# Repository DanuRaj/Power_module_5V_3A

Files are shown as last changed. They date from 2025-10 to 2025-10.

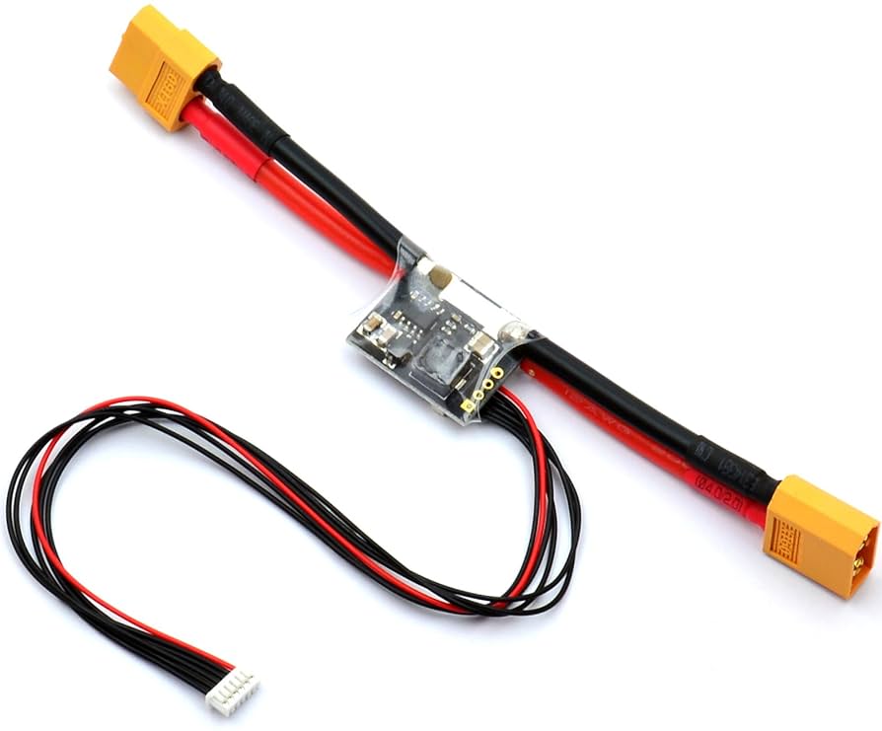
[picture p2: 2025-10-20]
Reference documents/APM BEC module image.jpg

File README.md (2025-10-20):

# Power_module_5V_3A
<p align="left">

</p> 

This power module takes power from the flight battery (usually 6 cell) and steps it down to a stable 5.25V output to power the flight controller. It measures the battery voltage and 
current draw and send this analog data to the flight controller.

## Board Function Description
- Voltage Regulator: A switching power supply (Buck Converter) convert the input voltage (input max 28V) to a steady 5.25V (3A max).
- Current Sensor: A high-side, unipolar current shunt monitor (INA139) from Texas Instruments, used to measure current upto 60A.
- Voltage Divider: A simple circuit scales the battery's high voltage down to a range that the flight controller's analog-to-digital converter (ADC) can safely read.

## Links
- Component Comparision, selection and budget calculation: https://docs.google.com/spreadsheets/d/1E6E3Z39MS1AMKON_rcoMTrBAKxuoQgl9/edit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
- Board version details: https://docs.google.com/spreadsheets/d/1RwYq9DlDa9_kEa9Yjs7iCPJi0Gea4oT7bDzQ82SCQtg/edit?usp=sharing
- Board fabrication batch details: https://docs.google.com/spreadsheets/d/1Ot-wO0kC-6jDttAs3GkX9LXFDDRmeL8QQExoFt7C394/edit?usp=sharing
- Block diagram: https://drive.google.com/file/d/1YQ6c-Lb43SASnWm7NJ7m4_MqnetjV_JF/view?usp=sharing

## Top and bottom images
<p align="left">


</p>

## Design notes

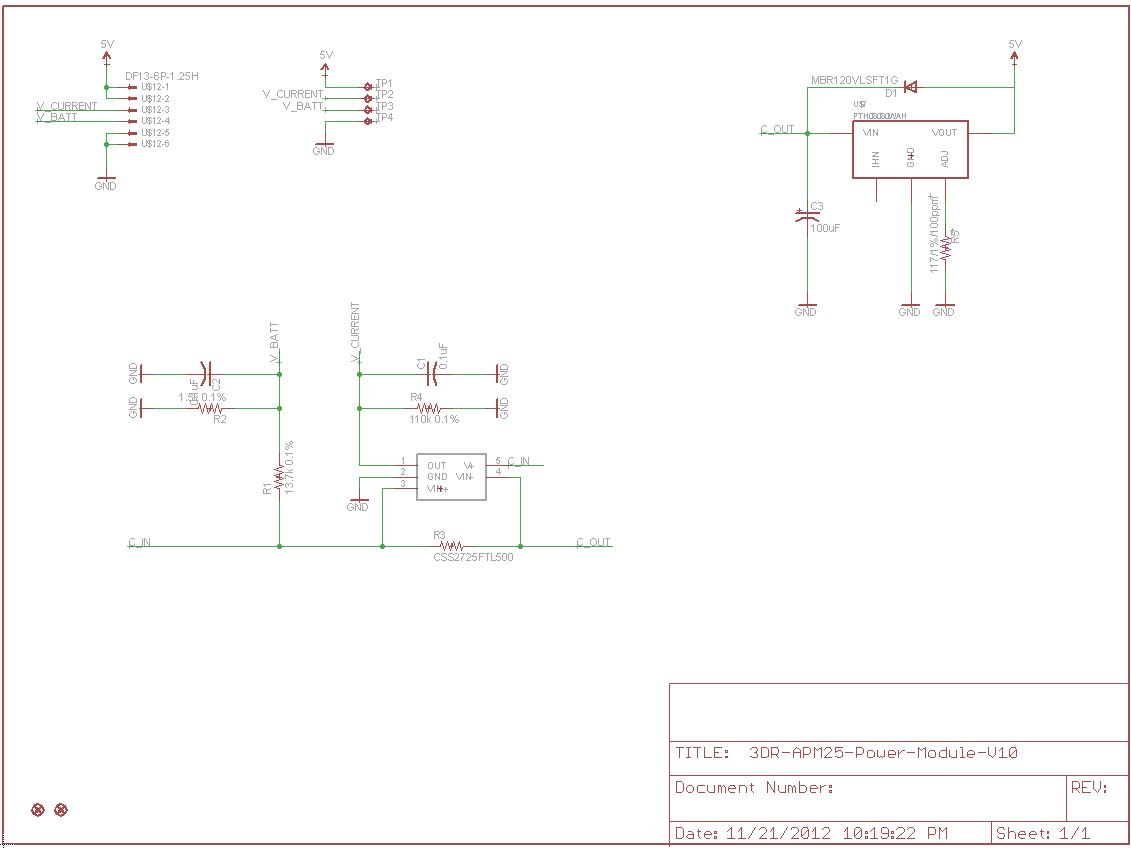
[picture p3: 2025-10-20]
Reference documents/024_21_apm-power-module-schematic.jpg

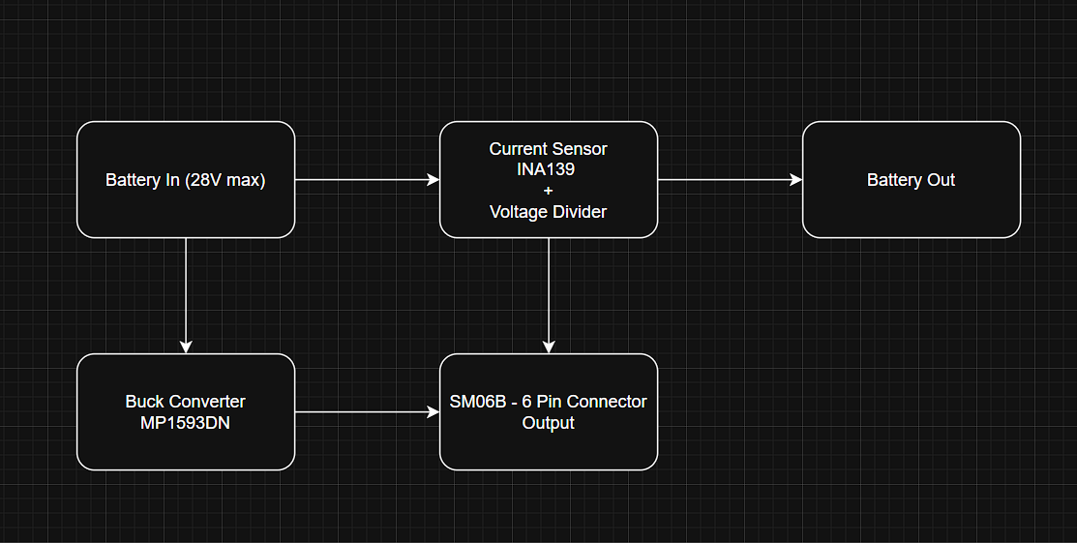
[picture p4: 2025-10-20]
Reference documents/Block Diagram.png

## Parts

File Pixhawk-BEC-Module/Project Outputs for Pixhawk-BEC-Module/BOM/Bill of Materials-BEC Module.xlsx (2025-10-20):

Name | Quantity | Designator | Footprint | MPN | Description
CC0402KRX7R9BB104 | 3 | C1, C2, C8 | CAP_0402 | CC0402KRX7R9BB104 | 50V 100nF X7R ±10% 0402 Multilayer Ceramic Capacitors MLCC - SMD/SMT ROHS
C0402C103K5RACTU | 2 | C3, C9 | CAP_0402 | C0402C103K5RACTU | Multilayer Ceramic Capacitors MLCC - SMD/SMT 50V 0.01uF X7R 0402 10%
CC1210KKX7R9BB106 | 2 | C4, C5 | CAP_1210 | CC1210KKX7R9BB106 | 50V 10uF X7R ±10% 1210 Multilayer Ceramic Capacitors MLCC - SMD/SMT ROHS
GRM32ER71E226ME15L | 2 | C6, C7 | CAP_1210 | GRM32ER71E226ME15L | 22 µF ±20% 25V Ceramic Capacitor X7R 1210 (3225 Metric)
SS34 | 1 | D1 | SMB_ONS | SS34 | Diode 40 V 3A Surface Mount DO-214AB (SMC)
SM06B-GHS-TB | 1 | J1 | CONN_SM06B-GHS-TB_JST | SM06B-GHS-TB | Connector Header Surface Mount, Right Angle 6 position 0.049" (1.25mm)
SRR1260-150M | 1 | L1 | IND_BOURNS_SRR1260 | SRR1260-150M | 15 µH Shielded Drum Core, Wirewound Inductor 5 A 27mOhm Max Nonstandard
PA2512FKE7T0U5E | 1 | R1 | RES_PA2512_YAG-L | PA2512FKE7T0U5E | 500 µOhms ±1% 3W Chip Resistor 2512 (6332 Metric) Anti-Sulfur, Automotive AEC-Q200, Current Sense, Moisture Resistant Metal Element
ERJ-2RKF1372X | 1 | R2 | RES_0402 | ERJ-2RKF1372X | Res Thick Film 0402 13.7K Ohm 1% 0.1W ±100ppm/°C Molded SMD Punched Carrier T/R
ERJ-2GEJ152X | 1 | R3 | RES_0402 | ERJ-2GEJ152X | Res Thick Film 0402 1.5K Ohm 5% 0.1W(1/10W) +/-200ppm/ßC SMD Automotive T/R
ERJ-2GEJ104X | 1 | R4 | RES_0402 | ERJ-2GEJ104X | Res Thick Film 0402 100K Ohm 5% 0.1W(1/10W) +/-200ppm/ßC SMD Automotive T/R
CRGP0402F33K | 1 | R5 | RES_0402 | CRGP0402F33K | Res Thick Film 0402 33K Ohm 1% 0.125W(1/8W) ±100ppm/C Pad SMD T/R Automotive AEC-Q200
CRGP0402F10K | 1 | R6 | RES_0402 | CRGP0402F10K | Res Thick Film 0402 10K Ohm 1% 0.125W(1/8W) ±100ppm/C Pad SMD T/R Automotive AEC-Q200
RK73H1ETTP7501F | 1 | R7 | RES_0402 | RK73H1ETTP7501F | Res Thick Film 0402 7.5K Ohm 1% 0.1W(1/10W) ±100ppm/C Pad SMD Automotive T/R
INA139NA/250 | 1 | U1 | DBV0005A_N | INA139NA/250 | 2.7 to 36V, 440kHz Variable gain current sense amplifier 5-SOT-23 -40 to 125
MP1593DN-LF-Z | 1 | U2 | SOIC8E_MNP | MP1593DN-LF-Z | 3A 28V 385KHz Step-Down Converter

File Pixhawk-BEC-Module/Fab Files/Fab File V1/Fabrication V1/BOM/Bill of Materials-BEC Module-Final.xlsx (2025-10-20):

Bill Of Materials |  |  |  | Bill of Materials for [Bill of Materials-BEC Module.BomDoc]
 |  |  | Source Data From: | Bill of Materials-BEC Module.BomDoc
 |  |  | Project: | Pixhawk-BEC-Module.PrjPCB
 |  |  | Variant: | No Variant
 |  | Report Date:(MM/DD/YY) | 2025-10-09
 |  | Print Date: (MM/DD/YY) | 2025-10-09
Line | Quantity | Designator | Description | Manufacturer 1 | Manufacturer Part Number 1
 | 3 | C1, C2, C8 | 50V 100nF X7R ±10% 0402 Multilayer Ceramic Capacitors MLCC - SMD/SMT ROHS |  | CC0402KRX7R9BB104
 | 2 | C3, C9 | Multilayer Ceramic Capacitors MLCC - SMD/SMT 50V 0.01uF X7R 0402 10% |  | C0402C103K5RACTU
 | 2 | C4, C5 | 50V 10uF X7R ±10% 1210 Multilayer Ceramic Capacitors MLCC - SMD/SMT ROHS |  | CC1210KKX7R9BB106
 | 2 | C6, C7 | 22 µF ±20% 25V Ceramic Capacitor X7R 1210 (3225 Metric) |  | GRM32ER71E226ME15L
 | 1 | D1 | Diode 40 V 3A Surface Mount DO-214AB (SMC) |  | SS34
 | 1 | J1 | Connector Header Surface Mount, Right Angle 6 position 0.049" (1.25mm) |  | SM06B-GHS-TB
 | 1 | L1 | 15 µH Shielded Drum Core, Wirewound Inductor 5 A 27mOhm Max Nonstandard |  | SRR1260-150M
 | 1 | R1 | 500 µOhms ±1% 3W Chip Resistor 2512 (6332 Metric) Anti-Sulfur, Automotive AEC-Q200, Current Sense, Moisture Resistant Metal Element |  | PA2512FKE7T0U5E
 | 1 | R2 | Res Thick Film 0402 13.7K Ohm 1% 0.1W ±100ppm/°C Molded SMD Punched Carrier T/R |  | ERJ-2RKF1372X
 | 1 | R3 | Res Thick Film 0402 1.5K Ohm 5% 0.1W(1/10W) +/-200ppm/ßC SMD Automotive T/R |  | ERJ-2GEJ152X
 | 1 | R4 | Res Thick Film 0402 100K Ohm 5% 0.1W(1/10W) +/-200ppm/ßC SMD Automotive T/R |  | ERJ-2GEJ104X
 | 1 | R5 | Res Thick Film 0402 33K Ohm 1% 0.125W(1/8W) ±100ppm/C Pad SMD T/R Automotive AEC-Q200 |  | CRGP0402F33K
 | 1 | R6 | Res Thick Film 0402 10K Ohm 1% 0.125W(1/8W) ±100ppm/C Pad SMD T/R Automotive AEC-Q200 |  | CRGP0402F10K
 | 1 | R7 | Res Thick Film 0402 7.5K Ohm 1% 0.1W(1/10W) ±100ppm/C Pad SMD Automotive T/R |  | RK73H1ETTP7501F
 | 1 | U1 | 2.7 to 36V, 440kHz Variable gain current sense amplifier 5-SOT-23 -40 to 125 |  | INA139NA/250
 | 1 | U2 | 3A 28V 385KHz Step-Down Converter |  | MP1593DN-LF-Z
 | 21

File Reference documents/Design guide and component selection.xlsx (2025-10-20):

APM-Pixhawk BEC Module
 |  |  |  |  | All the components are selected according to this design
 |  |  |  |  |  |  |  |  |  | Vin | I out | Vout |  | Unit Price |  | Digikey |  | Operating Temp
 |  |  |  |  | Buck converter |  | MP1593 | Datasheet (https://www.monolithicpower.com/en/documentview/productdocument/index/version/2/document_type/Datasheet/lang/en/sku/MP1593/document_id/212/) |  | 4.75-28V | 3A | Adjustable |  | $3.42 |  | MP1593DN-LF-Z |  | .-40°C to +125°C
 |  |  |  |  | Current sensor |  | INA169 | Datasheet (https://www.ti.com/lit/ds/symlink/ina169.pdf?ts=1758474172726) |  | 2.7-60V |  |  |  | $3.10 |  | INA169NA/250 |  | –40°C to +85°C
 |  |  |  |  |  |  | INA139 | Datasheet (https://www.ti.com/lit/ds/symlink/ina169.pdf?ts=1758523395236) |  | 2.7-40V |  |  |  | $2.40 |  | INA139NA/250 |  | .-40°C to +125°C
 |  |  |  |  | APM Pixhawk BEC Module Specs |  |  |  |  |  |  |  |  |  |  |  |  | In pixhawk design
 |  |  |  |  | Maximum input voltage of 18V (4S lipo) |  |  |  |  |  |  |  | 6 Cells | 4.4*6 = 26.4V |  |  |  | 30V -> 3V
Reference Design Link (https://rcmodelytt.sk/apm-power-modul/)
 |  |  |  |  | Maximum of 90 Amps (but only capable of measuring up to 60 Amps) |  |  |  |  |  |  |  | For current monitoring |  |  |  |  | 60A -> 3V
Board size 24*20mm
 |  |  |  |  | Provides 5.37V and 2.25Amp power supply to the autopilot |  |  |  |  |  |  |  | 5.3V output
Buck converter design
Inductor selection |  |  |  |  |  | Part Number |  |  | Inductance |  | Irms |  | Isat |  | DCR |  | Price
 |  |  |  |  |  | CDRH104RNP-100NC |  |  | 10uH |  | 3.8A |  | 4.4A |  | 35mOhm |  | $1.16
 |  |  |  |  |  | 744770115 |  |  | 15uH |  | 5A |  | 6A |  | 27mOhm |  | $2.40
 |  |  |  |  |  | SRR1260-150M |  |  | 15uH |  | 5A |  | 4.6A |  | 27mOhm |  | $1.01
Vout = 5.3V
Fs = 385kHz
Vin = 22.2V (3.7*6) |  | From 6 cell battery pack
IL p-p = 0.9A
DCR < 30mOhm |  | For inductor power loss < 0.1W
Calculated Inductance (L) = 11.6uH
Vout set |  |  |  |  |  | Pin configuration
R2 | 10K |  |  |  |  | EN | For automatic startup leave EN disconnected
R1 | 33K
Vfb | 1.22V
Vout | 5.25V
Current sensor design
Shunt resistor |  |  | Vout of current measurement |  |  |  |  |  | Vout of voltage measurement
0.5mOhm |  |  |  |  |  |  |  |  |  |  |  | R1 = 13.7K
 | V drop | Power loss
10A | 5mV | 0.05W |  |  |  |  |  |  |  |  |  | R2 = 1.5K
20A | 10mV | 0.2W | Rs = 0.5mOhm |  | RL = 100K
30A | 15mV | 0.45W
40A | 20mV | 0.8W | Is | Vout
 |  |  | 10A | 0.5V
 |  |  | 20A | 1V
 |  |  | 30A | 1.5V
 |  |  | 40A | 2V |  |  |  |  |  | Vin | Vout
 |  |  | 60A | 3V |  |  |  |  | 4.4*6 | 26.4V | 2.6V
 |  |  |  |  |  |  |  |  | 3.7*6 | 22.2V | 2.19V
 |  |  |  |  |  |  |  |  | 3.4*6 | 20.2V | 1.99V
 |  |  |  |  |  |  |  |  | 3*6 | 18V | 1.77V

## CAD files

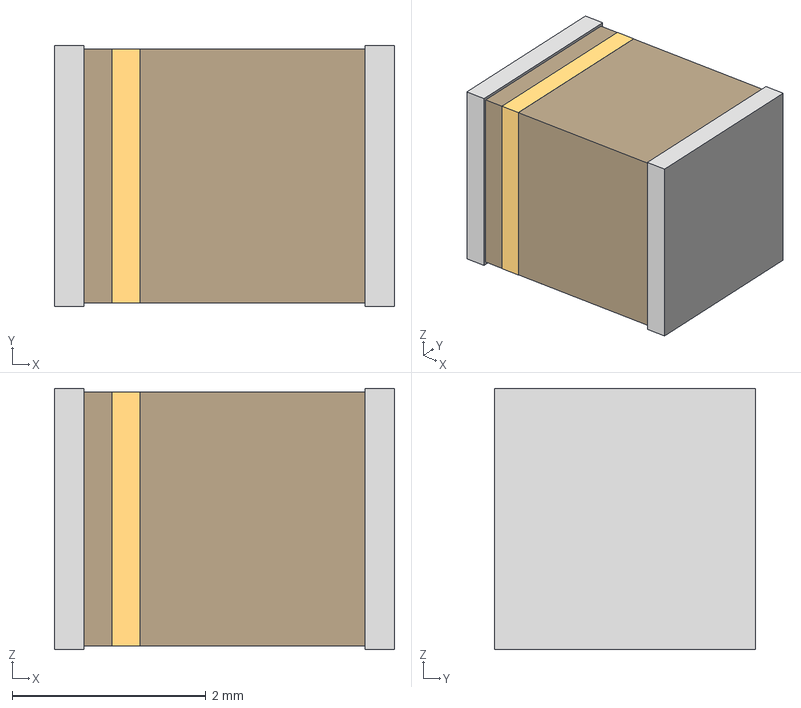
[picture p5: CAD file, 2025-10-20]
Pixhawk-BEC-Module/Downloaded component libs/GRM32ER71E226ME15L/AltiumDesigner/CAP_GRM32E_MUR.step
3.51 x 2.69 x 2.69 mm

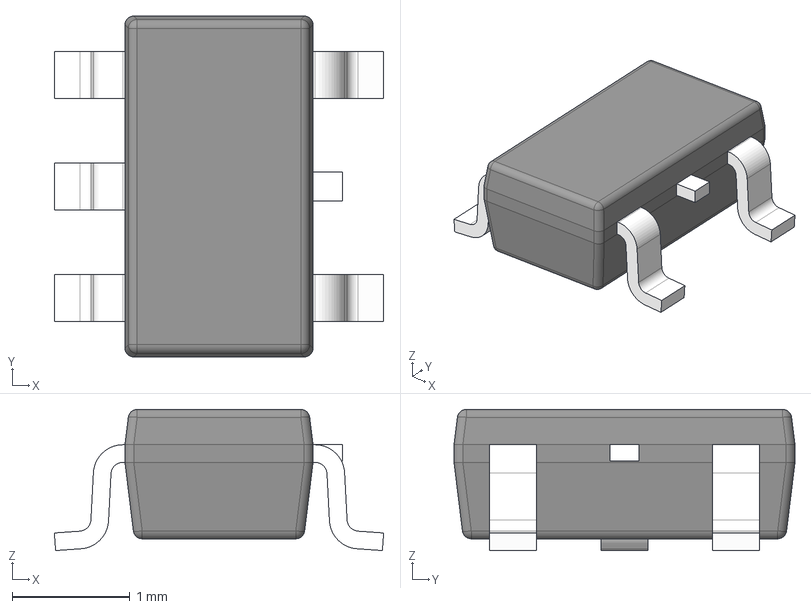
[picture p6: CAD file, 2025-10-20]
Pixhawk-BEC-Module/Downloaded component libs/INA139NA_250/DBV0005A.stp
2.80 x 2.90 x 1.20 mm
BODY-SOT
LEAD-SOT x 5
LEAD-DUMMY

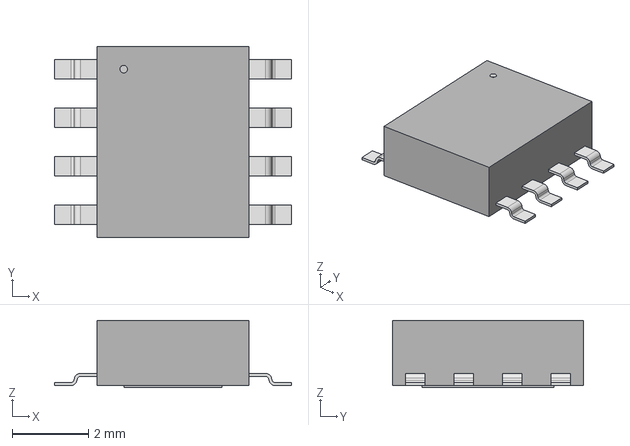
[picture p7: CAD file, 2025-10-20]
Pixhawk-BEC-Module/Downloaded component libs/MP1593DN_LF_Z/AltiumDesigner/SOIC8E_MNP.step
6.20 x 5.00 x 1.75 mm

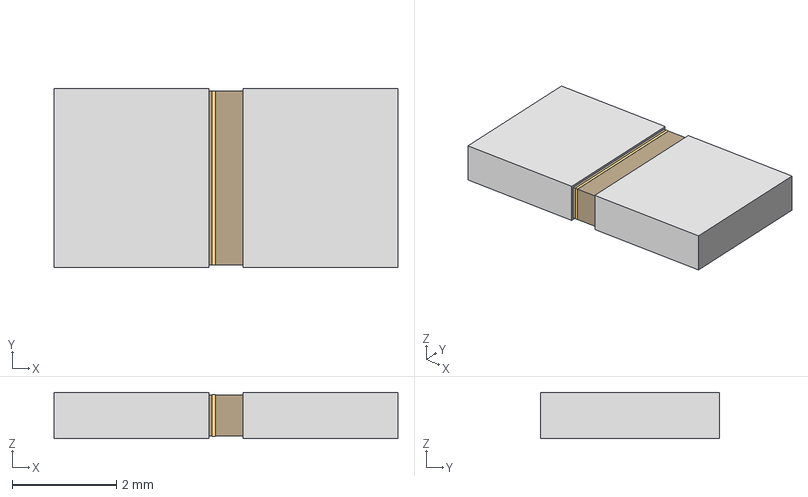
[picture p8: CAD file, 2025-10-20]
Pixhawk-BEC-Module/Downloaded component libs/PA2512FKE7T0U5E/AltiumDesigner/RES_PA2512_YAG.step
6.60 x 3.43 x 0.889 mm

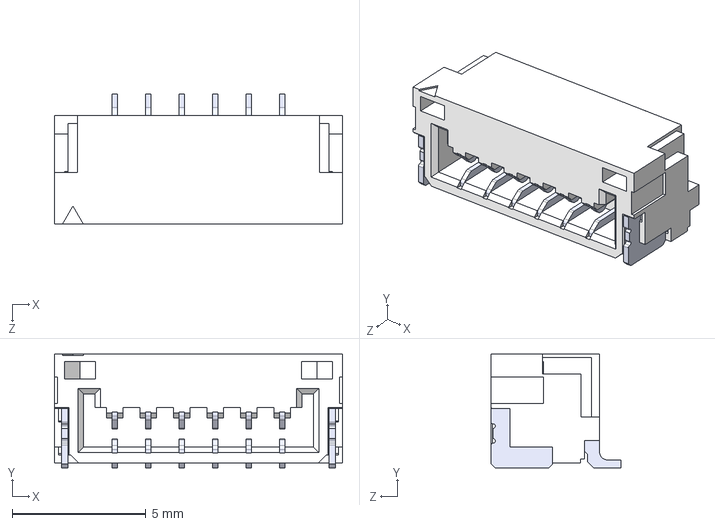
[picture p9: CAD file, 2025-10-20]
Pixhawk-BEC-Module/Downloaded component libs/SM06B_GHS_TB/SM06B-GHS-TB.STEP
10.8 x 4.25 x 4.85 mm
SMxB-GHS-TB_06
pin x 6

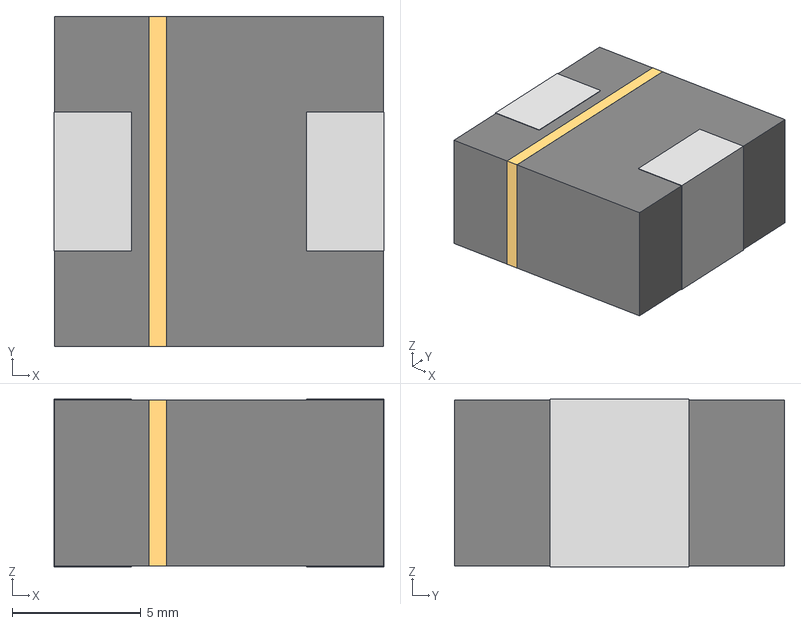
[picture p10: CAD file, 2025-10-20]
Pixhawk-BEC-Module/Downloaded component libs/SRR1260_150M/AltiumDesigner/IND_BOURNS_SRR1260.step
12.8 x 12.8 x 6.50 mm

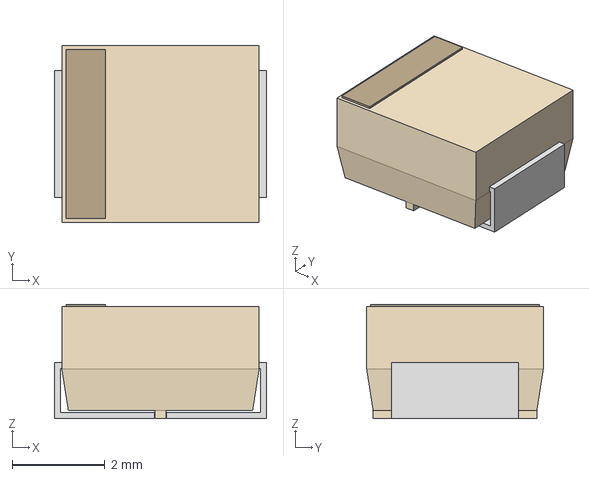
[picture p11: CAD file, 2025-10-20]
Pixhawk-BEC-Module/Downloaded component libs/SS34/AltiumDesigner/SMB_ONS.step
4.57 x 3.81 x 2.46 mm

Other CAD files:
Pixhawk-BEC-Module/Downloaded component libs/GRM32ER71E226ME15L/CAP_GRM32E_MUR.step
Pixhawk-BEC-Module/Downloaded component libs/MP1593DN_LF_Z/SOIC8E_MNP.step
Pixhawk-BEC-Module/Downloaded component libs/PA2512FKE7T0U5E/RES_PA2512_YAG.step
Pixhawk-BEC-Module/Downloaded component libs/SS34/SMB_ONS.step

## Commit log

2025-10-07 fab files updated
    [Bill of Materials-BEC Module.xlsx, CAP_GRM32E_MUR.step, DBV0005A.stp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]
2025-10-08 added top and bottom GND pour and updated gerber files
    [PCB1.PcbDoc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]
2025-10-10 BoM updated
    [Bill of Materials-BEC Module-Final.xlsx]
2025-10-28 changed the pad sizes and updated fabrication outputs
    [PCB1.PcbDoc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]
2025-10-28 copied fab files to fab output folder
    [Bill of Materials-BEC Module-Final.xlsx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]
2025-10-28 gerber updated
    [PCB1.PcbDoc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]
